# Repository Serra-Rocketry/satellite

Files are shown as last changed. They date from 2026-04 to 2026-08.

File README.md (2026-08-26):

# Helike — PocketQube Mission (#213 - LASC 2026)





PocketQube satellite project by **Serra Rocketry Team** for the Latin American
Space Challenge (LASC) 2026. Focus on bioinspired autorotating recovery system
(SRAB) and LoRa-based telemetry triangulation.

## Overview

The Helike satellite collects flight telemetry (IMU, barometric data, GPS)
and transmits it via LoRa radio at 915 MHz to a ground station. The payload
is a passive autorotating recovery system inspired by maple seed aerodynamics.

## Features

- BME280 environmental sensor (temperature, pressure, humidity)
- ICM-20602 6-axis IMU (accelerometer + gyroscope)
- NEO-8M GPS receiver (position, altitude, time)
- RFM95W LoRa radio (915 MHz, SF7, 125 kHz)
- SD card (primary) + LittleFS (fallback) data logging
- 18-field CSV telemetry packet format
- Vertical velocity computation (EMA filter)
- Automatic apogee detection
- Data validation (NaN + physical range checks)
- 5 Hz sample rate

## Hardware Requirements

| Component | Model | Interface |
|---|---|---|
| MCU | ESP32-C3 Super Mini | - |
| Barometric | BME280 (or BMP280) | I2C (0x76) |
| IMU | ICM-20602 | I2C (0x69) |
| GPS | NEO-8M | UART (9600 baud) |
| Radio | RFM95W | SPI (915 MHz) |
| Storage | microSD card + LittleFS | SPI / flash |

## Software Requirements

- [PlatformIO](https://platformio.org/) (VS Code extension or CLI)
- Python 3.8+ (for analysis scripts in `extras/`)

Dependencies managed automatically by PlatformIO:

| Library | Version |
|---|---|
| sandeepmistry/LoRa | ^0.8.0 |
| Adafruit BME280 Library | ^2.2.4 |
| Adafruit BMP280 Library | ^2.6.8 |
| TinyGPSPlus | ^1.0.3 |

## Quick Start

### 1. Build the Firmware

```bash
pio run -e helike_esp32c3
```

### 2. Upload to Satellite

```bash
pio run -e helike_esp32c3 -t upload --upload-port /dev/ttyACM0
```

### 3. Monitor Serial Output

```bash
pio device monitor -b 115200
```

### 4. Run Unit Tests

```bash
pio test -e native
```

## Repository Structure

```text
satellite/
├── src/                       # Main firmware source
│   ├── main.cpp               # Entry point (setup + loop)
│   ├── config.h               # Global configuration
│   ├── sensors/               # Sensor drivers (ISensor interface)
│   │   ├── BME280Sensor.h/.cpp
│   │   ├── ICM20602Sensor.h/.cpp
│   │   └── GPSSensor.h/.cpp
│   └── modules/               # System modules
│       ├── LoRaModule.h/.cpp
│       ├── TelemetryModule.h/.cpp
│       ├── FilesystemModule.h/.cpp
│       ├── LEDModule.h/.cpp
│       └── BuzzerModule.h/.cpp
├── lib/calc/                  # Header-only calculation library
│   ├── SensorData.h
│   ├── VerticalVelocity.h
│   ├── ApogeeDetection.h
│   └── DataValidation.h
├── test/                      # Native unit tests (Unity)
│   ├── test_vz/
│   ├── test_apogee/
│   └── test_validation/
├── test_hardware/             # Hardware validation sketches
│   ├── sensor/                # Isolated sensor tests
│   ├── integration/           # Multi-sensor integration
│   └── storage/               # Filesystem tests
├── docs/                      # Documentation
│   ├── software.md
│   ├── hardware.md
│   ├── firmware.md
│   ├── flowchart.md
│   └── adr/                   # Architecture Decision Records
├── extras/
│   └── wing-analysis/         # SRAB aerodynamic study
├── hardware/                  # CAD and PCB files
└── platformio.ini             # PlatformIO configuration
```

## Documentation

| Document | Description |
|---|---|
| [Software Architecture](docs/software.md) | Module structure, data flow, validation |
| [Hardware Specs](docs/hardware.md) | Pinout, sensors, LoRa configuration |
| [Firmware Guide](docs/firmware.md) | Build, upload, testing, debug |
| [Flowcharts](docs/flowchart.md) | System diagrams (Mermaid) |
| [ADRs](docs/adr/) | Architecture Decision Records |
| [Hardware Tests](test_hardware/docs/) | Bench guides and checklists |
| [Wing Analysis](extras/wing-analysis/docs/) | SRAB aerodynamics |

## Development Workflow

1. Validate individual sensors in `test_hardware/sensor/`
2. Run integration tests in `test_hardware/integration/`
3. Execute unit tests: `pio test -e native`
4. Run aerodynamic studies: `extras/wing-analysis/`
5. Consolidate results in technical documentation
6. Integrate final firmware

## Quality Tools

```bash
# Markdown linting
npx -y markdownlint-cli "README.md" "docs/**/*.md" "test_hardware/docs/**/*.md" "extras/**/*.md" "hardware/**/*.md"

# Native unit tests
pio test -e native
```

## License

MIT License — see LICENSE file for details.

## Team

**Serra Rocketry Team** — Missão Helike (#213 - LASC 2026)

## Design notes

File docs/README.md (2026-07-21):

# Documentation

Technical documentation for the Helike PocketQube satellite (#213 - LASC 2026).

## Contents

| Document | Description |
|---|---|
| [software.md](software.md) | Software architecture, modules, and data flow |
| [hardware.md](hardware.md) | Hardware specifications, pinouts, and BOM |
| [firmware.md](firmware.md) | Firmware build and deployment guide |
| [flowchart.md](flowchart.md) | System flowcharts (Mermaid diagrams) |
| [adr/](adr/) | Architecture Decision Records |

## Architecture Decision Records

| ADR | Title | Status |
|-----|---|---|
| [ADR-001](adr/001-no-fsm-no-sleep.md) | No FSM, No Sleep Mode | Accepted |
| [ADR-002](adr/002-sd-littlefs-fallback.md) | SD Primary + LittleFS Fallback | Accepted |
| [ADR-003](adr/003-tinygpsplus-vs-manual.md) | TinyGPSPlus vs Manual NMEA | Accepted |
| [ADR-004](adr/004-platformio-vs-arduino-ide.md) | PlatformIO vs Arduino IDE | Accepted |

## Related Documentation

- [Hardware tests](../test_hardware/docs/) — Bench guides and checklists
- [Wing analysis](../extras/wing-analysis/docs/) — SRAB aerodynamic study
- [Mechanical assembly](../hardware/mechanical/README.md) — CAD file structure

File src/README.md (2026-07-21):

# Firmware Source Code

Main source code for the Helike PocketQube satellite.

## Organization

### `sensors/`
Contains drivers and abstractions for the hardware sensors. Every sensor implements the `ISensor` interface for consistent data retrieval.
- `BME280Sensor`: Pressure, Temperature, Humidity.
- `ICM20602Sensor`: Accelerometer and Gyroscope.
- `GPSSensor`: Position and Timing.

### `modules/`
High-level system modules that orchestrate hardware and logic:
- `LoRaModule`: Manages radio transmission and packet formatting.
- `TelemetryModule`: Collects data from sensors and prepares it for storage/transmission.
- `FilesystemModule`: Handles dual-storage logic (SD card primary, LittleFS fallback).
- `LEDModule` & `BuzzerModule`: System status and alert indicators.

## Entry Point

The `main.cpp` file handles the system initialization and the primary execution loop, coordinating the telemetry sampling and transmission cycles.

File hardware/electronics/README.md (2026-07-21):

# Electronics Hardware

This directory contains the electrical design files for the Helike satellite, including schematics and PCB layouts.

## Project Structure

```text
electronics/
├── electronics.kicad_pro   # KiCad project file
├── electronics.kicad_sch   # Circuit schematic
├── electronics.kicad_pcb    # PCB layout
├── electronics.pretty/      # Custom footprints
└── Library.pretty/         # Local component library
```

## Design Notes

- **MCU**: ESP32-C3 Super Mini
- **Interface**: I2C for sensors, SPI for LoRa and SD Card, UART for GPS.
- **Tools**: Designed using KiCad 8.0.

For the mechanical integration of the PCB, see `hardware/mechanical/electronics/`.

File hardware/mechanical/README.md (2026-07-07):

# Mechanical Assembly

Arquivos de modelagem 3D e montagem mecanica do satelite.

## Estrutura de pastas

```
mechanical/
├── assembly/        — montagens gerais (.SLDASM)
├── chassis/         — corpo principal (.SLDPRT)
├── electronics/     — PCBs, bateria, suportes de montagem (.SLDPRT)
├── standoff/        — parafusos, porcas, separadores (.SLDPRT)
├── srab/
│   ├── assembly/    — montagens do SRAB (.SLDASM)
│   └── parts/       — pecas do SRAB (.SLDPRT)
├── README.md
```

## Convencoes

- `.SLDPRT` — partes nativas SolidWorks
- `.SLDASM` — montagens nativas SolidWorks
- `.STEP` — formato neutro para compartilhamento (AP214)
- `.STL` — para impressao 3D / visualizacao rapida
- Nomes em lowercase, snake_case, sem espacos; sufixo `_v2`, `_v3` para revisoes

## Como contribuir

1. Salve `.SLDPRT`/`.SLDASM` nativo + `.STEP` neutro + `.STL` (se impressivel)
2. Mantenha o STEP neutro sempre atualizado como fonte de verdade para corte/CAM
3. Adicione nota aqui quando subir nova revisao

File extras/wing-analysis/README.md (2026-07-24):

# Helike #213 — SRAB Deploy Simulation

Modelagem e simulação do sistema de recuperação SRAB (Samara Recovery
System) para o PocketQube Helike #213 — LASC 2026.

## Notebook principal

[`notebooks/01_simulacao_deploy_srab.ipynb`](notebooks/01_simulacao_deploy_srab.ipynb)
— Pipeline completo de simulação:

| Fase | Veículo | Método |
|---|---|---|
| Stage 1 | Foguete completo | RocketPy `Flight` (subida até apogeu) |
| Stage 2 | Foguete vazio | RocketPy `Flight` + `initial_solution` (descida c/ paraquedas) |
| Stage 3 | PocketQube (payload) | `SRABRecovery.simulate_from_flight()` (descida SRAB) |

## Estrutura

```
wing-analysis/
├── notebooks/
│   └── 01_simulacao_deploy_srab.ipynb   ← Notebook principal (único)
├── src/
│   ├── samara_pq_simulation.py           ← Módulo de simulação SRAB
│   ├── rocketpy_samara/
│   │   ├── srab_recovery.py              ← Recuperação SRAB
│   │   └── plotting.py                   ← Plotagem LRR
│   └── ...
├── geometry/
│   └── Asa3.DXF                          ← Geometria da asa SRAB
├── docs/
│   ├── readme-explicativo.md
│   └── ...
└── data/                                 ← Dados de motor, etc.
```

## Requisitos

- Python 3.10+
- `rocketpy` (>= 1.x)
- `numpy`, `matplotlib`, `scipy`, `folium`

## Execução

```bash
cd notebooks/
jupyter notebook 01_simulacao_deploy_srab.ipynb
```

Ou via nbconvert:

```bash
jupyter nbconvert --to notebook --execute \
  notebooks/01_simulacao_deploy_srab.ipynb \
  --output executed.ipynb
```

## Parâmetros principais

- **Target velocidade**: 20 m/s ÷ SF 1.5 = **13.33 m/s** (SF sobre limite estrutural/LASC)
- **Raio otimizado**: **7.88 cm** (ala Asa3.DXF, 2 asas, β=5°)
- **Paraquedas foguete**: Main (cd_s=7.2) acionado no apogeu (drogue removido)
- **Atmosfera**: GFS forecast (vento real do modelo)
- **Motor**: Cesaroni Pro75 M1670 (placeholder — Calisto)

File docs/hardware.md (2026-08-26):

# Hardware Specifications

## Platform

- **Microcontroller**: ESP32-C3 Super Mini (RISC-V single-core, 400KB RAM)
- **Radio**: RFM95W LoRa module (915 MHz, SPI)
- **GPS**: NEO-8M (UART, 9600 baud)
- **Sensors**: BME280 (I2C, primary) with BMP280 fallback, ICM-20602 (I2C)
- **Storage**: SD card slot (GPIO10, SPI) + LittleFS flash (fallback)
- **Actuators**: LED (GPIO3), Active buzzer (GPIO0)

## Pinout (ESP32-C3 Super Mini — per schematic)

```text
                     ESP32-C3 Super Mini
  ┌─────────────────────────────────────────────┐
  │  0  BUZZER ─────────── Active buzzer        │
  │  1  RESET ──────────── RFM95W (LoRa RST)    │
  │  2  DIO0 ───────────── RFM95W (LoRa IRQ)    │
  │  3  LED ────────────── Status indicator     │
  │  4  SCK ─── SPI ────── RFM95W + SD Card     │
  │  5  MISO ── SPI ────── RFM95W + SD Card     │
  │  6  MOSI ── SPI ────── RFM95W + SD Card     │
  │  7  NSS ────────────── RFM95W (LoRa CS)     │
  │  8  SDA ─── I2C ────── BME280 + ICM-20602   │
  │  9  SCL ─── I2C ────── BME280 + ICM-20602   │
  │ 10  CS_SD ──────────── SD Card (CS)          │
  │ 20  TX_GPS ── UART ─── GPS NEO-8M (TX)      │
  │ 21  RX_GPS ── UART ─── GPS NEO-8M (RX)      │
  └─────────────────────────────────────────────┘
```

### Pin Summary Table

| GPIO | Label | Function / Protocol | Connected To |
|---|---|---|---|
| 0 | BUZZER | GPIO (digitalWrite) | Active buzzer |
| 1 | RESET | GPIO output | RFM95W (pin 6, RST) |
| 2 | DIO0 | GPIO input (IRQ) | RFM95W (pin 14, DIO0) |
| 3 | LED | GPIO output | Status indicator |
| 4 | SCK | SPI Clock | RFM95W + SD Card |
| 5 | MISO | SPI MISO | RFM95W + SD Card |
| 6 | MOSI | SPI MOSI | RFM95W + SD Card |
| 7 | NSS | SPI Chip Select | RFM95W (LoRa CS) |
| 8 | SDA | I2C Data | BME280 + ICM-20602 |
| 9 | SCL | I2C Clock | BME280 + ICM-20602 |
| 10 | CS_SD | SPI Chip Select | SD Card module (CS) |
| 20 | TX_GPS | UART RX (ESP input) | GPS NEO-8M (TX pin) |
| 21 | RX_GPS | UART TX (ESP output)| GPS NEO-8M (RX pin) |

### Notes

- **SPI bus is shared** between RFM95W and SD Card (same MOSI/MISO/SCK). Each has a
  dedicated CS pin: LoRa CS = GPIO7, SD CS = GPIO10.
- **I2C bus is shared** between BME280/BMP280 and ICM-20602. Both use address 0x76
  (BME/BMP) and 0x69 (ICM).
- **UART**: GPS uses Serial1 with custom pins RX=GPIO20, TX=GPIO21.
- **Buzzer**: Active buzzer (built-in oscillator) — controlled via `digitalWrite`.
  No PWM required.

## Sensor Specifications

### BME280/BMP280 (Environmental — BMP280 fallback)

| Parameter | Value |
|---|---|
| Interface | I2C |
| Address | 0x76 (SDO=GND) or 0x77 (SDO=VCC)  |
| Pressure range | 300-1100 hPa |
| Temperature range| -40 to +85°C |
| Humidity range | 0-100% RH (BME280 only, N/A on BMP280) |
| I2C speed | 400 kHz (Fast Mode) |

**Fallback strategy**: The firmware tries BME280 first. If not found, falls back
to BMP280. `getHumidity()` returns NAN when using BMP280 (no humidity sensor).

### ICM-20602 (IMU)

| Parameter | Accelerometer | Gyroscope |
|---|---|---|
| Interface | I2C | I2C |
| Address | 0x69 | 0x69 |
| Range | ±16g (±157 m/s²) | ±2000°/s (±34.9 rad/s)|
| Resolution  | 16-bit | 16-bit |
| Sensitivity | 2048 LSB/g | 16.384 LSB/°/s |

### NEO-8M (GPS)

| Parameter | Value |
|---|---|
| Interface | UART (Serial1) |
| Baud rate | 9600 |
| Protocol | NMEA 0183 |
| Update rate | 1 Hz (default) |
| Fix types | 2D, 3D |
| Min satellites | 4 (3D fix) |

### RFM95W (LoRa Radio)

| Parameter | Value |
|---|---|
| Interface | SPI |
| Frequency | 915 MHz |
| Sync Word | 0xF3 |
| Spreading Factor| 7 |
| Bandwidth | 125 kHz |
| Coding Rate | 4/5 |
| CRC | Enabled |
| TX Power | 20 dBm |

## LoRa Compatibility

Satellite and receiver MUST use identical LoRa parameters:

| Parameter | Satellite | Receiver |
|---|---|---|
| Frequency | 915 MHz | 915 MHz  |
| Sync Word | 0xF3 | 0xF3 |
| SF | 7 | 7 |
| BW | 125 kHz | 125 kHz  |
| CR | 4/5 | 4/5 |
| CRC | Enabled | Enabled  |

## Known ESP32-C3 Issues

### 1. tone() / LEDC Bug
The Arduino core for ESP32-C3 has a bug where `tone()` fails with
`ledc: ledc_get_duty(745): LEDC is not initialized`.
**Fix**: Use `ledcSetup()` + `ledcAttachPin()` + `ledcWrite()` instead of `tone()`.
(The buzzer module uses `digitalWrite` since the active buzzer has a built-in
oscillator — no PWM needed. The bug remains relevant for passive buzzers or
PWM-driven peripherals.)

### 2. USB CDC Serial
`Serial.println()` output does not appear unless the firmware is compiled with:
```
-D ARDUINO_USB_MODE=1 -DARDUINO_USB_CDC_ON_BOOT=1
```
Without these flags, Serial uses UART0 (pins GPIO20/21) instead of USB CDC.

### 3. I2C Bus Recovery
`resetI2C()` (toggling SCL via pinMode/digitalWrite) breaks the I2C peripheral
configuration on ESP32-C3. **Do not use GPIO-level recovery with TwoWire.**

### 4. Shared SPI Bus: SD + LoRa (bench session 2026-08-24)

The SD card and RFM95W share SCK/MISO/MOSI. Three rules discovered during
first power-on testing (full rationale in ADR-005):

- **Initialize SPI exactly once** in `main.cpp`, with CS pins HIGH, before
  any library touches the bus. Libraries (`SD`, LoRa sandeepmistry) call
  `SPI.begin()` internally on their own `begin()`; a second init corrupts
  the peripheral state.
- **Boot order: LoRa first, storage after.** An SD mount attempt before
  radio configuration makes every subsequent `endPacket()` fail. The
  reverse order is safe: after a failed `SD.begin()`, TX still works.
- **Never call `SD.end()` or re-`begin()` SPI at runtime.** Both tear down
  the peripheral shared with the radio.

Additional SD notes:
- SD mount needs ≥74 wake-up clocks with CS high before CMD0;
  `FilesystemModule::setupSD()` sends them manually.
- If `appendLine()` fails 5× consecutively in flight, the module degrades
  to LittleFS automatically (no code path requires SD).
- Cards must be FAT32; exFAT mounts fail with `f_mount failed (13)`.
- **Wiring**: long untwisted dupont jumpers between ESP and RFM95W cause
  intermittent SPI corruption (worked/failed depending on cable position).
  Keep SPI leads short (<10 cm); if twisted pairs are used, twist each
  signal with GND, never signal-with-signal.

### 5. LoRa sandeepmistry Library API Notes

- `LoRa.endPacket()` returns **1 on success**, 0 on failure. Check
  `== 1`. (A pre-existing inverted check reported every successful TX as
  an error for the module's whole early life.)
- Use `LoRa.setSPI(SPI)` before `LoRa.setPins()` so the library shares
  the bus instance initialized by `main.cpp`.

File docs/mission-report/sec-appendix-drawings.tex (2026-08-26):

\textbf{\hfill\break
}

\textbf{Engineering Drawings and Optional Appendix}

This appendix contains the revision-controlled technical drawings and
optional supporting material for the Helike \#213 subsystems.

\subsection{Drawing List}

\begin{center}
{\small
\setlength{\tabcolsep}{6pt}
\begin{tabularx}{\linewidth}{>{\raggedright}p{6cm}X}
\toprule
\textbf{Drawing / Document} & \textbf{Status} \\
\midrule
Electrical schematic (KiCad, U1--U6, SW1--SW3) & Final (Figure 1) \\
PCB layout & In progress \\
SRAB wing geometry (Asa1/Asa2/Asa3) & Final (DXF + ABS prototypes) \\
PocketQube 1P mechanical structure & In progress \\
ESP32-C3 pinout & Final \\
Integrated assembly & In progress \\
\bottomrule
\end{tabularx}
}
\end{center}

\subsection{Optional Appendices}

\subsubsection{SRAB Wing Geometry}

The wing geometries evolved through three design iterations, driven
by the simulation-to-field comparison loop described in Section 4:

\begin{itemize}
\item \textbf{Asa1} — 4 wings, first prototype: v$_{impact}$ =
  10.33~m/s, 444.9~rpm, 6.1$^{\circ}$.
\item \textbf{Asa2} — 4 wings, increased area and realignment:
  v$_{impact}$ = 10.05~m/s, 439.1~rpm, 11.9$^{\circ}$ — candidate
  configuration.
\item \textbf{Asa3} — 2 wings (mission final): reduced mass and
  complexity, $v \approx 20$~m/s, within the SCSM 20--45~m/s range.
\end{itemize}

% TODO: insert dimensional drawings of the SRAB wings (DXF-derived),
% the PCB layout, the mechanical structure and the integrated assembly
% as they become available.

\subsubsection{Test Data}

% TODO: include CSV logs, telemetry plots, simulation-vs-field
% comparison plots, photos of Asa1/Asa2 prototypes and drop-test
% videos once the instrumentation campaign (Test 4, ~200 m) is
% complete.

\subsubsection{Computational Simulation}

The 4th-order autorotation model, calibrated parameters, simulation
scripts (RocketPy + SRAB extension) and the geometry heat-map are
maintained in the repository under \texttt{extras/wing-analysis/}.
The full-flight simulation (Dédalo + SRAB) is documented in the
notebook \texttt{01\_simulacao\_dedalo.ipynb}.

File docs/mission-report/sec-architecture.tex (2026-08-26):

\begin{enumerate}
\def\labelenumi{\arabic{enumi}.}
\setcounter{enumi}{1}
\item
  \textbf{System Architecture and Concept of Operations}
\end{enumerate}

\subsection{System Architecture}

Helike \#213 is a PocketQube 1P (50$\times$50$\times$50~mm, $\sim$200~g)
whose central subsystem is the SRAB — the bioinspired autorotative
recovery system. The satellite is organized in five functional blocks:

\begin{center}
{\small
\setlength{\tabcolsep}{6pt}
\begin{tabularx}{\linewidth}{>{\raggedright}p{3cm}X}
\toprule
\textbf{Block} & \textbf{Components} \\
\midrule
Recovery (SRAB) & 2 autorotative wings (Asa3), passive deployment \\
EPS & Li-Ion 1300~mAh + BMS, RBF pin, 2 kill switches \\
Avionics & ESP32-C3 Super Mini, single 5~Hz polling loop \\
Sensors & BME280 (pressure/temp/humidity), ICM-20602 (6-axis IMU) \\
Telemetry & LoRa RFM95W 915~MHz, GPS NEO-8M, SD + LittleFS \\
\bottomrule
\end{tabularx}
}
\end{center}

\begin{figure}[htbp]
\centering
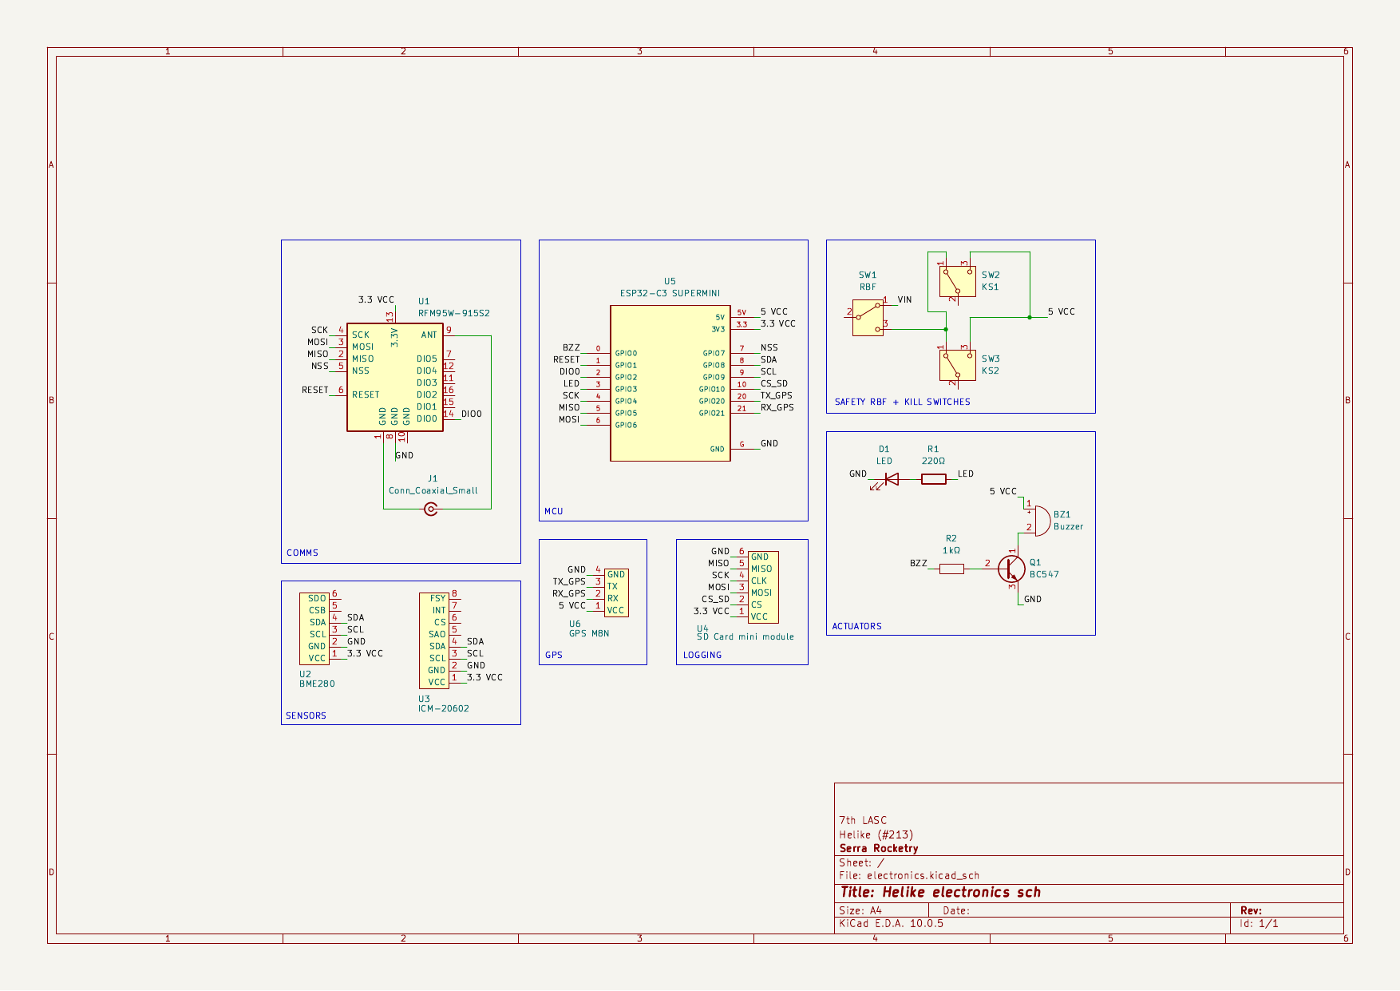
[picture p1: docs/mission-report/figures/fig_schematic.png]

\caption{Electrical schematic of Helike \#213 (KiCad). U1: ESP32-C3
Super Mini; U2: LoRa RFM95W-915S2; U3: BME280; U4: ICM-20602; U5: GPS
NEO-8M; U6: SD card module; SW1/SW2: kill switches (Z axis); SW3: RBF
pin; J1: SMA antenna; D1/BZ1: status LED and buzzer.}
\label{fig:schematic}
\end{figure}

\subsection{Subsystem Descriptions}

\subsubsection{Recovery (SRAB)}

The SRAB is a passive recovery system composed of 2 autorotative wings
(Asa3 geometry), stowed during flight and deployed by ejection. They
convert the potential energy of the fall into rotational kinetic
energy, slowing the satellite to a predicted terminal velocity of
13.33~m/s --- the $V_F = 20/1.5$~m/s design target, applying a 1.5
safety factor to the LASC 20~m/s limit. There are no actuators: no
servo, no pyrotechnics, no deployment electronics. Recovery does not
depend on software at all, so it works even with total loss of the
avionics. The two-wing configuration keeps the mechanism simple and
light; losing a single wing is a mission-critical degradation, so the
design relies on the robustness of the geometry and on the drop-test
evidence accumulated across the Asa1/Asa2/Asa3 iterations.

\subsubsection{Electrical Power System}

Energy comes from a 1300~mAh Li-Ion battery protected by a BMS that
covers overcharge, overdischarge, short-circuit and overcurrent. With
an average draw of about 145~mA, the predicted autonomy exceeds 5~h, a
margin of roughly two times the SCSM requirement of 4~h. Safety is
handled by two kill switches (SW1/SW2, NC contacts wired in parallel,
Z axis) plus the RBF pin
(SW3), which cuts all energy when inserted. The satellite only powers
on at ejection, keeping it independent from the rocket as required by
REC 10.1.1.

\subsubsection{Avionics and Telemetry}

At the core sits an ESP32-C3 Super Mini, a single-core RISC-V
microcontroller running a single synchronous 5~Hz polling loop, with
no state machine and no RTOS scheduler. A BME280 measures pressure,
temperature and humidity, and an ICM-20602 six-axis IMU adds
acceleration and angular rate; together they feed the 5~Hz telemetry
packet and the SRAB rotation analysis. Telemetry goes down through the
LoRa RFM95W at 915~MHz (SF7, 125~kHz bandwidth, 20~dBm, sync word
0xF3, CRC enabled), transmit-only, while a GPS NEO-8M records the
post-landing position. Flight data are written to an SD card with
automatic LittleFS fallback on the internal flash, and three ground
beacons measure RSSI for trilateration once the satellite is on the
ground. Impact detection, the buzzer and the low-power beacon mode are
planned for a future firmware revision and are not yet part of the
flight software.

\subsection{Concept of Operations}

From a technology-development standpoint, the ConOps doubles as the
flight-test plan for the SRAB: each arc exercises one stage of the
recovery system --- powered-off safety while stowed (SAFE), ejection
and power-on (BOOST), passive deployment and autorotation (DESCENT),
and ground location (POST-LANDING) --- and the descent telemetry is
the primary evidence for validating the aerodynamic model against
real flight data.

The satellite's behavior follows the physical flight profile in four
arcs, and the firmware mirrors them through a single polling loop
rather than a phase-detecting state machine. The first arc is
\emph{inert}: the satellite starts in SAFE, with the kill switches and
the RBF pin inserted, and stays completely powered off until ejection.
The second arc begins at \emph{ejection}: the satellite powers on,
initializes the sensors and attempts a first GPS fix, then samples and
transmits through the boost and coast phases while the rocket climbs
toward apogee. The third arc is the \emph{descent}: at apogee the
satellite leaves the rocket, the two SRAB wings deploy passively ---
no actuator, no command required --- and the descent is governed
entirely by autorotation while the 5~Hz telemetry packet streams
rotation rate, descent velocity and the monitored Launch Readiness
Review parameters. The fourth arc is \emph{post-landing}: impact
detection, the buzzer and a low-power beacon mode are planned for a
future firmware revision; the current firmware simply keeps
transmitting periodic packets with RSSI and GPS position until the
battery is exhausted or the recovery team arrives.

\begin{figure}[htbp]
\centering
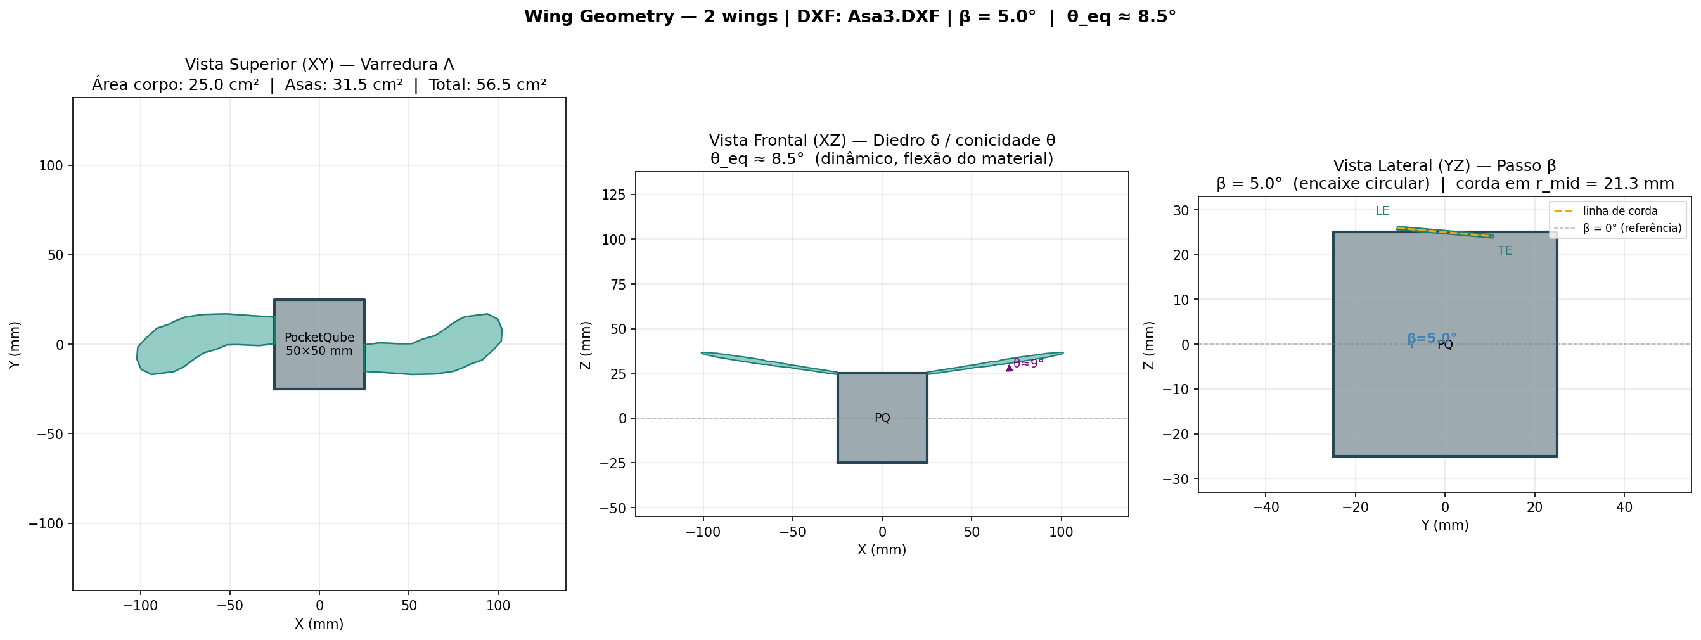
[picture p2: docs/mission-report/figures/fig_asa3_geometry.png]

\caption{SRAB wing geometry views (Asa3): three orthogonal projections
of the wing + hub assembly used in the computational simulation and
drop tests.}
\label{fig:wing-geometry}
\end{figure}

% TODO: replace placeholder figure above with the final CAD renders /
% exploded view once available. fig_asa3_geometry.png is the
% computational geometry used in the SRAB model.

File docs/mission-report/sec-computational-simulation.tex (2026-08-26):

\begin{enumerate}
\def\labelenumi{\arabic{enumi}.}
\setcounter{enumi}{3}
\item
  \textbf{Computational Simulation}
\end{enumerate}

\subsection{Theoretical Background}

\subsubsection{Samara Autorotation}

The SRAB is inspired by the autorotation of samara seeds (\emph{Acer
rubrum}). The seed geometry places the center of mass at one end and
the aerodynamic center at the other, generating a torque imbalance
that produces stable conical rotation during fall. The resulting
motion is a steady autorotation state where the descent rate is
substantially lower than the ballistic terminal velocity of the same
mass [2].

\subsubsection{Leading-Edge Vortex (LEV)}

At high incidence angles and rotation rates, a stable leading-edge
vortex forms on the wing upper surface, increasing the effective lift
coefficient beyond the thin-airfoil limit. This LEV effect is the key
to the samara's efficiency and is modeled through an augmented lift
coefficient in the blade element formulation.

\subsubsection{Reduced-Order Rigid-Body Model}

The descent is modeled with a 4th-order reduced Newton-Euler
formulation [3], with state vector (Eq.~\ref{eq:state}):

\begin{equation}
\mathbf{x} = [\theta,\ \dot{\theta},\ \dot{\phi},\ v_0]^T
\label{eq:state}
\end{equation}

where $\theta$ is the conicity angle, $\dot{\phi}$ the rotor spin rate
and $v_0$ the vertical descent velocity. The aerodynamic loads are
computed with the Blade Element Method (BEM) (Eq.~\ref{eq:bem}):

\begin{equation}
dF = \frac{1}{2}\rho\, w(r)\, \|U\|^2 \left[C_L(\alpha),\; C_D(\alpha)\right] dr
\label{eq:bem}
\end{equation}

with the thin-airfoil lift curve and the induced-drag model
(Eq.~\ref{eq:coefs}):

\begin{equation}
C_L = 2\pi\sin\alpha, \qquad
C_D = C_L \sin\alpha + C_{D0}
\label{eq:coefs}
\end{equation}

where $C_{D0} = 1.0$ is the flat-plate drag coefficient and the LEV
contribution is embedded through the $f_{factor} = 0.3$ correction in
the lift build-up [5].

\subsection{Simulation Methodology}

The validation pipeline is an iterative loop: model, simulate,
prototype, drop, compare, and iterate on the geometry. We start from a
4th-order rigid-body dynamics model with a Blade Element Method
aerodynamic model, implemented in RocketPy [6] with SRAB extension
modules. The descent is then simulated from the real apogee of the
launch vehicle, the Dédalo rocket, in the same GFS atmosphere and with
the same payload mass as the actual flight. PETG 3D-printed wings
(Asa1, Asa2 and Asa3 geometries) are dropped from controlled heights
with instrumentation, and the measured terminal velocity, spin rate
and cone angle are compared against the simulation. The wing geometry
is updated between test cycles based on that comparison, which is how
the design improved from one campaign to the next.

\subsubsection{Launch Vehicle Model — Dédalo}

The Dédalo rocket (used as the launch vehicle for Helike \#213) is
modeled in RocketPy:

\begin{center}
{\small
\setlength{\tabcolsep}{6pt}
\begin{tabular}{>{\raggedright}p{5.2cm}l}
\toprule
\textbf{Parameter} & \textbf{Value} \\
\midrule
Total mass (with payload) & 5.100 kg \\
Empty mass (Stage 2) & 4.900 kg \\
Payload mass (Helike \#213) & 0.200 kg \\
Diameter & 106 mm \\
Motor & SolidMotor, 926 N peak, 2.82 s burn \\
Motor data points & 95 \\
Atmosphere & GFS (real, launch-day forecast) \\
Launch site & lat $-21.94305$, lon $-48.95409$, elev 478 m \\
\bottomrule
\end{tabular}
}
\end{center}

\subsection{Results}

\subsubsection{Stage 1 — Dédalo Ascent (with payload)}

\begin{center}
\begin{tabular}{ll}
\toprule
\textbf{Parameter} & \textbf{Value} \\
\midrule
Apogee & 1520 m AGL (1996 m ASL) \\
Time to apogee & 17.83 s \\
Maximum velocity & 205.3 m/s (0.59 Mach) \\
Maximum acceleration & 106.7 m/s$^2$ (10.9 g) \\
Rail departure & 0.47 s at 18.9 m/s \\
\bottomrule
\end{tabular}
\end{center}

\subsubsection{Stage 2 — Dédalo Empty Descent (parachute CdS = 10.0)}

\begin{center}
\begin{tabular}{ll}
\toprule
\textbf{Parameter} & \textbf{Value} \\
\midrule
Maximum descent velocity & 17.8 m/s \\
Total descent time & 183.5 s \\
Impact position (relative) & x $= -139.7$ m, y $= +43.2$ m \\
\bottomrule
\end{tabular}
\end{center}

\subsubsection{Stage 3 — SRAB Descent from Real Apogee}

The SRAB simulation is initialized at the real apogee of Stage 1
(1520.5 m AGL, $v_z \approx 0$), with the optimized wing radius for
the target impact velocity $V_F^{target} = V_{F,max}/FS =
20/1.5 = 13.33$ m/s:

\begin{center}
\begin{tabularx}{\linewidth}{>{\raggedright}p{5.2cm}X}
\toprule
\textbf{Parameter} & \textbf{Value} \\
\midrule
Wing geometry & Asa3 (2 wings), optimized radius 79.7 mm \\
Release altitude & 1520.5 m AGL \\
Impact velocity & 13.33 m/s \\
Descent time & 111.4 s \\
Equilibrium cone angle $\theta_{eq}$ & 8.6$^{\circ}$ \\
Impact spin rate & 477 RPM \\
Total drift & 184.3 m \\
Impact position (relative) & x $= -67.5$ m, y $= +171.5$ m \\
LASC descent criterion & Target $V_F = V_{F,max}/FS = 20/1.5 = 13.33$ m/s; simulated impact 13.33 m/s (PASS, FS 1.5) \\
\bottomrule
\end{tabularx}
\end{center}

Note that the release occurs at the true apogee of the Dédalo flight
(1520.5~m AGL), about 1.4\% above the 1500~m AGL deployment guideline
of REC 10.1.5; the margin assessment is part of the Launch Readiness
Review.

\begin{figure}[htbp]
\centering
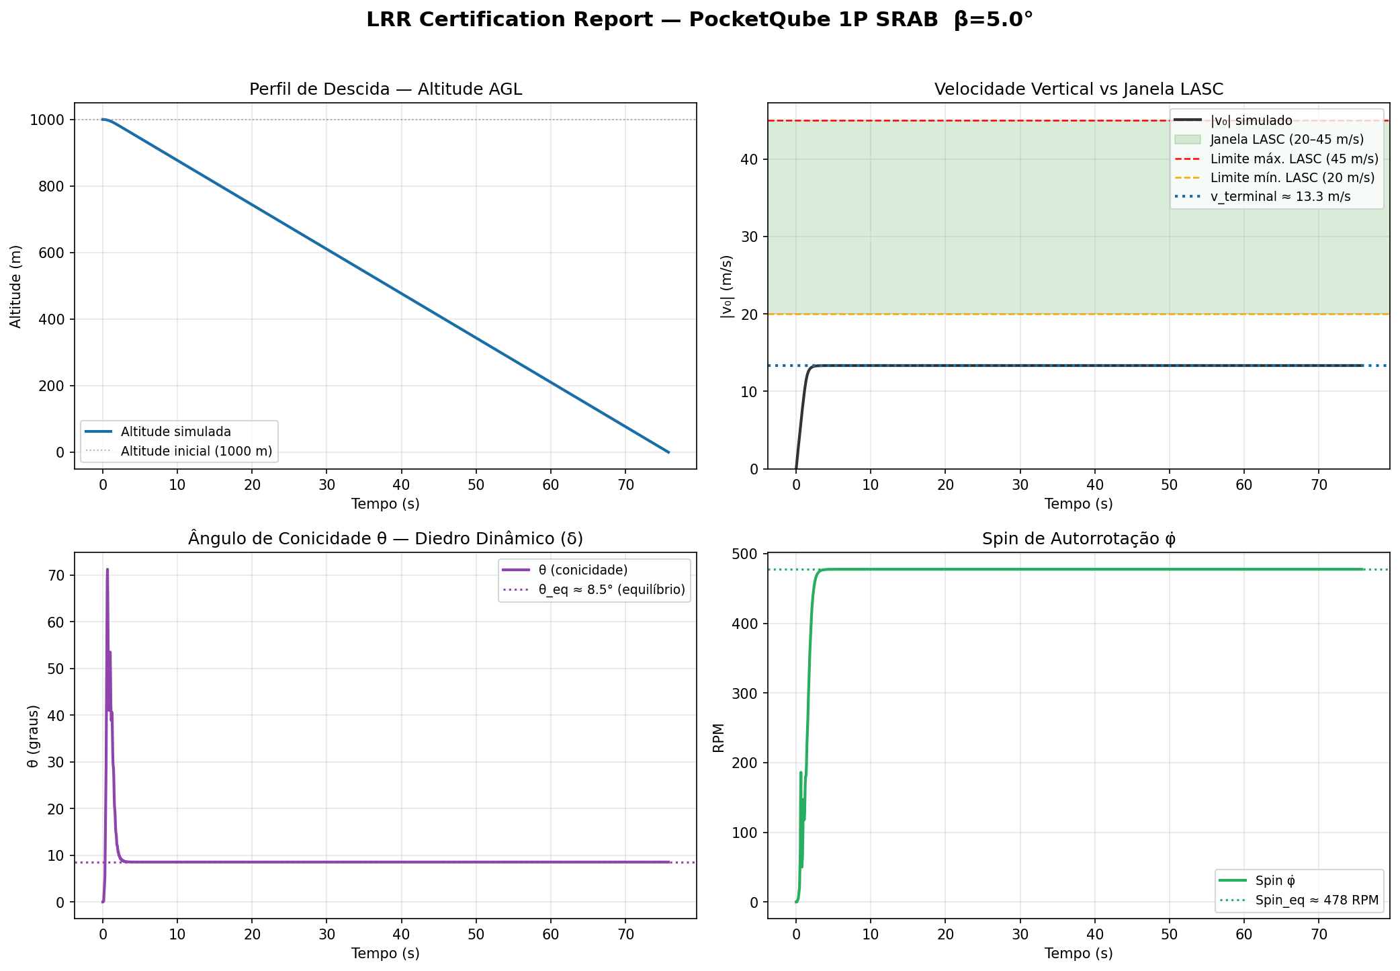
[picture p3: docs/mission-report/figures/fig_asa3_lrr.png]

\caption{LRR certification dashboard for the SRAB descent from the
real apogee: altitude profile, vertical velocity, cone angle
$\theta$, and autorotation spin rate.}
\label{fig:lrr-asa3}
\end{figure}

\begin{figure}[htbp]
\centering
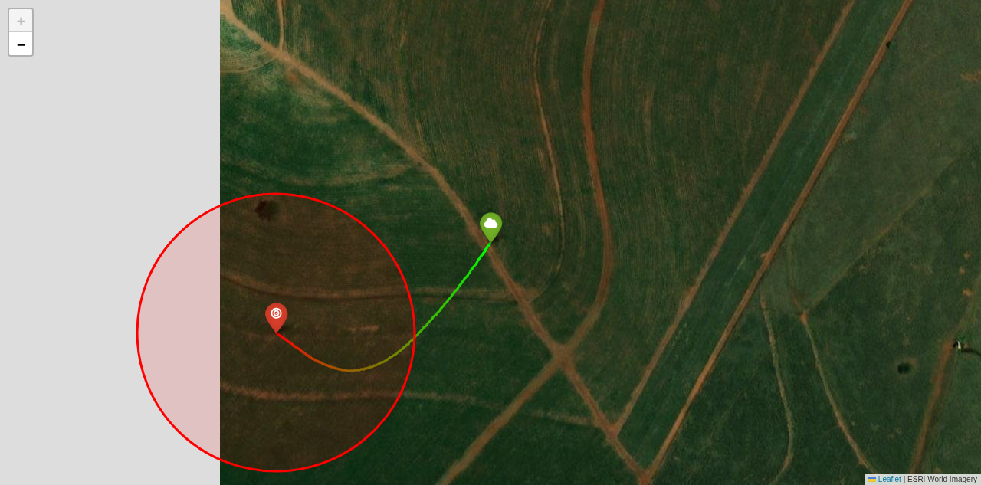
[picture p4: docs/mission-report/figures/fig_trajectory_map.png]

\caption{Satellite view of the simulated SRAB descent trajectory over
the Dédalo launch site: release point (green marker) at apogee and
predicted impact point (red marker, 100~m radius circle) downrange;
the trajectory line is colored by altitude.}
\label{fig:trajectory-map}
\end{figure}

\subsubsection{SRAB vs. Parachute Comparison}

A flat circular parachute ($\varnothing$200 mm, $C_D = 1.5$) was
simulated in the same GFS atmosphere, same release conditions and same
payload mass, as a benchmark:

\begin{center}
\begin{tabular}{lrrr}
\toprule
\textbf{Parameter} & \textbf{SRAB} & \textbf{Parachute} & \textbf{Ratio} \\
\midrule
Impact velocity (m/s) & 13.33 & 8.48 & 1.57$\times$ \\
Descent time (s) & 111.4 & 174.6 & 0.64$\times$ \\
Total drift (m) & 131.2 & 204.6 & 0.64$\times$ \\
Impact energy (J) & 17.8 & 7.2 & 2.47$\times$ \\
Terminal velocity (SL) (m/s) & 13.33 & 8.24 & 1.62$\times$ \\
\bottomrule
\end{tabular}
\end{center}

\begin{figure}[htbp]
\centering
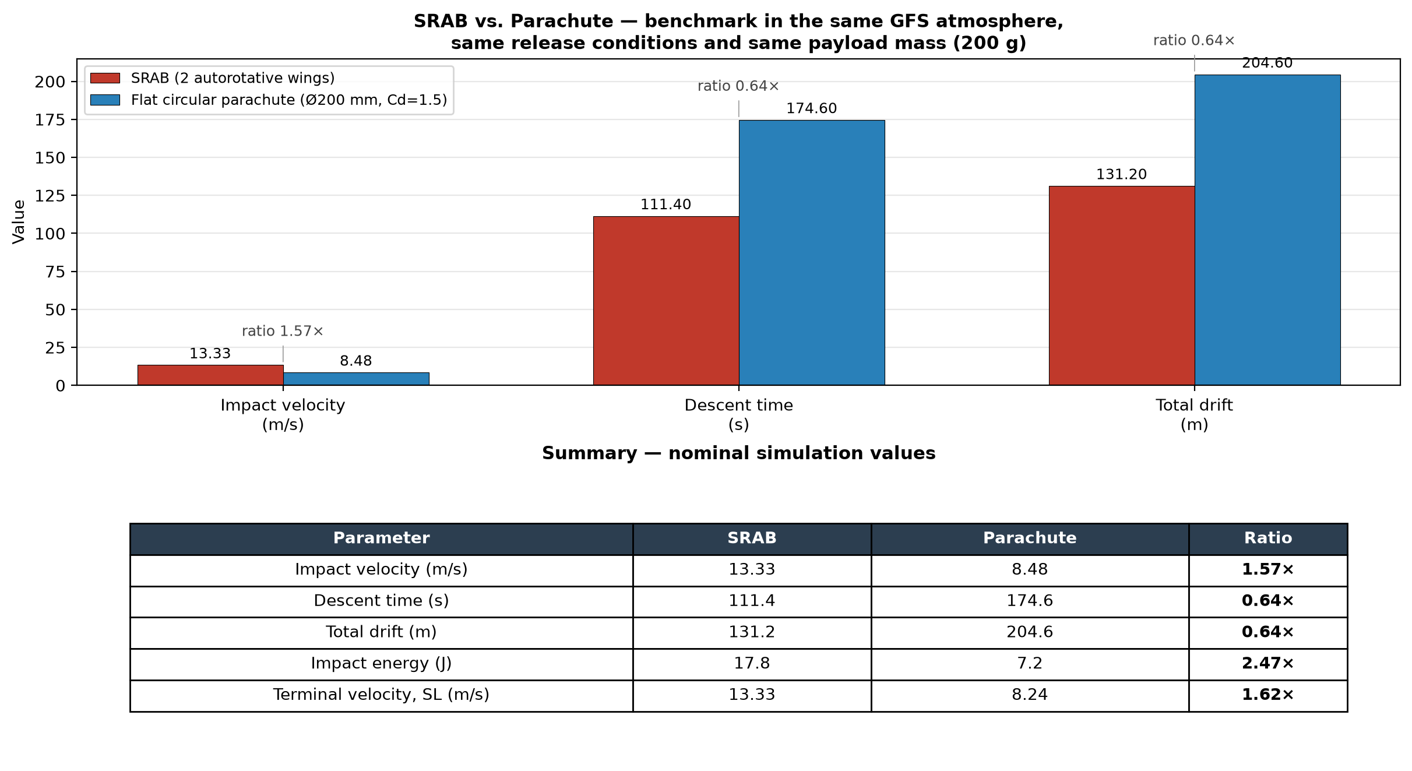
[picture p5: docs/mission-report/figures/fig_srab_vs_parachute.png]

\caption{SRAB vs. parachute benchmark in the same GFS atmosphere, same
release conditions and same payload mass (200~g): impact velocity,
descent time and total drift (bars) and full numerical summary
(table). Values match the comparison table above.}
\label{fig:srab-vs-parachute}
\end{figure}

The SRAB achieves a 36\% shorter descent time and 36\% lower drift
than the parachute, at the cost of a higher impact velocity and
energy — both still well below the 20~m/s LASC limit. The shorter
descent reduces wind exposure (drift), which is the dominant factor
for recovery accuracy on miniaturized satellites.

\subsubsection{Robustness: Monte Carlo Analysis}

A Monte Carlo analysis with 100 iterations of the Asa3 2-wing
configuration, released from the real simulated apogee, assessed the
descent under atmospheric dispersion: the impact velocity stayed at
$13.33 \pm 0.31$~m/s (P5 12.78, P95 13.87), the descent time at
$110.97 \pm 2.53$~s, the spin rate at $475.9 \pm 12.8$~rpm and the
equilibrium cone angle at $8.63 \pm 0.67^{\circ}$ — every iteration
below the 20~m/s LASC limit, confirming the 1.5 safety factor.

\subsubsection{Experimental Drop Tests}

Three instrumented drop-test campaigns validated the model:

\begin{center}
\begin{tabular}{llll}
\toprule
\textbf{Test} & \textbf{Geometry} & \textbf{v impact} & \textbf{Spin / Cone} \\
\midrule
Test 1 & Asa1, 4 wings & 10.33 m/s & 306.8 rpm / 13.5$^{\circ}$ \\
Test 2 & Asa2, 4 wings & 10.05 m/s & 306.9 rpm / 24.4$^{\circ}$ \\
Test 3 & Asa3, 4 wings & 12.90 m/s & 372.0 rpm / 17.2$^{\circ}$ \\
\bottomrule
\end{tabular}
\end{center}

Test 2 (Asa2, 4 wings, wing area 122.28~cm$^2$) increased the wing
area by 12\% and reduced the impact velocity from 10.33 to 10.05~m/s
(4\_PU), becoming the intermediate candidate. Test 3 (Asa3, 4 wings,
1000~m drop) reached steady autorotation at 12.90~m/s in 78.03~s,
with $\theta_{eq} = 17.22^{\circ}$ and 371.98~rpm, dissipating 99.15\%
of the impact energy (ENMC consolidated data).

\begin{figure}[htbp]
\centering
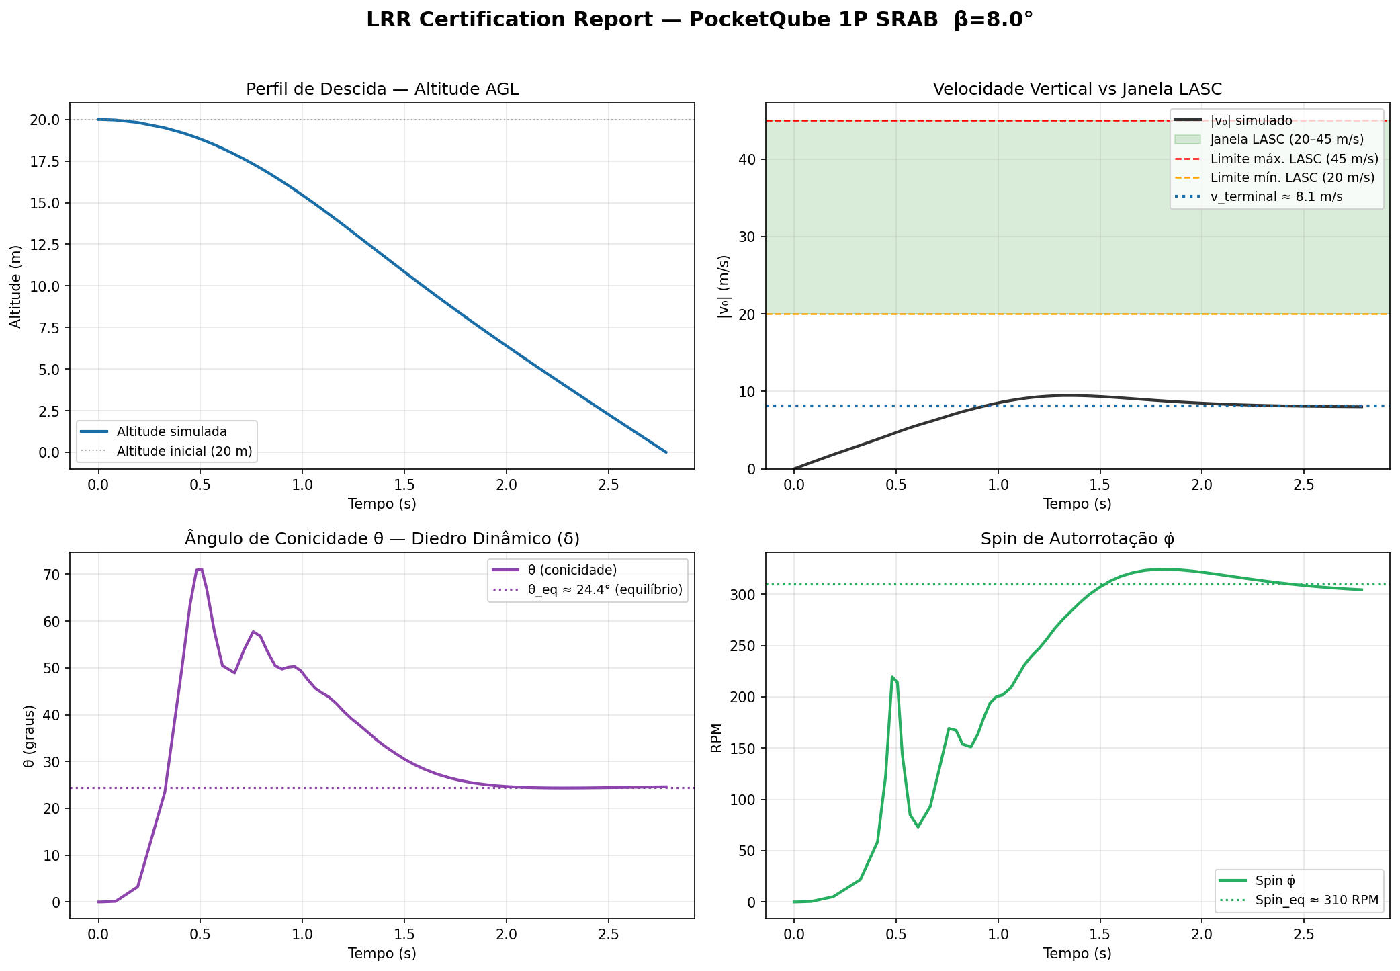
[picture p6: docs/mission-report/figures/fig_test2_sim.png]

\caption{Drop test 2 (Asa2, 4 wings) LRR dashboard: measured descent
profile, vertical velocity, cone angle and spin rate.}
\label{fig:test2-lrr}
\end{figure}

Test 3 (Asa3, 4 wings) also validated the onboard electronics, with
the SRAB instrumented to record rotation with the flight IMU; at a
1000~m drop it reached steady autorotation at 12.90~m/s in 78.03~s,
with $\theta_{eq} = 17.22^{\circ}$ and 371.98~rpm, dissipating 99.15\%
of the impact energy (ENMC consolidated data).

\subsubsection{Geometry Comparison and Final Choice}

A comparative simulation of Asa2 (4 wings) vs. Asa3 (2 wings) showed
10.05 vs. 13.33~m/s terminal velocity after the radius optimization.
The Asa3 2-wing configuration (optimized aerodynamic radius
79.7~mm) was chosen as the final configuration for the mission: it
reaches the 20/1.5~m/s design target with a 1.5 safety factor on the
LASC 20~m/s limit, while offering lower mass and complexity than the
4-wing versions.

% TODO: Test 4 (~200 m drop) is the next step for quantitative
% aerodynamic validation of the Asa3 2-wing configuration.

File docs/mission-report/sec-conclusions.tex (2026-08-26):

\begin{enumerate}
\def\labelenumi{\arabic{enumi}.}
\setcounter{enumi}{4}
\item
  \textbf{Conclusions and Lessons Learned}
\end{enumerate}

\subsection{Conclusions}

The Helike \#213 mission demonstrates that a bioinspired autorotative
recovery system (SRAB) is a viable, simpler and more robust
alternative to conventional parachutes for 1P PocketQubes. The SRAB
reaches the LASC regulatory impact velocity with a fully passive
mechanism, with no actuators, no pyrotechnics and no software
dependency. The computational model, built on a 4th-order rigid body
with BEM and a LEV correction, reproduces the measured drop-test
behavior with enough fidelity for design decisions, and the full
flight simulation, from the Dédalo launch vehicle to the SRAB descent
under real GFS conditions, certifies the recovery. Against a
conventional parachute, the SRAB shortens the descent by 36\% and cuts
total drift by 36\%, which improves recovery accuracy at the cost of a
higher, yet compliant, impact energy. Finally, the three-filter review
(SCSM compliance, Murphy analysis, timeline discipline) proved to be
an effective engineering framework: it caught the non-parachute
notification requirement (REC 10.2.1), drove the redundancy decisions
in firmware and hardware, and kept the project aligned with the
competition deadlines.

Above all, the mission treats LASC not merely as a competition but as
the operational proving ground of the SRAB technology: the September
flight is the first full-scale, instrumented test of a passive
samara-inspired recovery system in the conditions for which it was
designed. The telemetry returned from the descent --- rotation rate,
descent velocity, impact conditions --- is the evidence that will
recalibrate the model parameters (e.g.\ $C_{D0}$ and the LEV
correction factor) and close the loop between simulation and flight,
advancing the SRAB from a computational concept to a flight-proven
technology available to future PocketQube missions.

\subsection{Lessons Learned}

LASC 2025 taught us that optimization without redundancy is a trap,
and every subsystem of Helike carries a backup path: SD with LittleFS,
LoRa with local storage, a hardware watchdog, and a passive recovery
system that does not depend on electronics at all. We learned that the
parachute is the weakest link in the recovery chain, and replacing it
with a passive aerodynamic mechanism removes the most failure-prone
element entirely. Iterative drop testing beat simulation alone: each
test cycle, from Asa1 to Asa2 to Asa3, produced a measurable
improvement in both the model and the design, and that
simulation-validated iteration loop became the core of the project
methodology. Compliance, we found, is a design input, not a formality;
the SCSM requirements on kill switches, RBF, autonomy and notification
shaped the hardware schematic and the firmware loop architecture from day one. On
the team side, the three-filter reviews force decisions backed by
evidence (videos, logs, bench tests), which accelerates the transfer
of knowledge from senior to new members: every filter review doubles
as training for the next generation of the team.

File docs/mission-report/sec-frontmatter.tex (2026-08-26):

\textbf{Abstract}

This report presents the development of the Helike \#213 1P PocketQube
satellite, designed by team Serra Rocketry (IPRJ-UERJ) for the
Satellite Challenge category of the 7th Latin American Space Challenge
(LASC 2026). The mission's central element is the SRAB (Bioinspired
Autorotative Recovery System, from the Portuguese \textit{Sistema de Recuperação
Autorrotativo Bioinspirado}) --- a passive, parachute-free recovery
mechanism based on the autorotation of samara (maple) seeds, which
offers predictable, modelable aerodynamic behavior without the
electromechanical sequencers, pyrotechnics and tangled lines that make
conventional parachutes fail. The satellite also carries a LoRa
communication system with RSSI trilateration from three ground
beacons, which helps locate the satellite after landing and supports
recovery rather than being the mission's main objective. The report
walks through the system architecture and concept of operations, the
physics of samara autorotation, three drop-test campaigns, and the
mathematical modeling and computational simulation of the descent from
the apogee of the team's Dédalo launch vehicle, validated with
RocketPy --- closing with the risk analysis (P $\times$ S matrix) and the pre-flight
validation plan.

\textbf{Authors}

Diego dos Santos Alves. \emph{Serra Rocketry, Instituto Politécnico da UERJ
(IPRJ-UERJ), Nova Friburgo, Rio de Janeiro, 28625-570, Brazil.}

Pedro Henrique Couto Silva. \emph{Serra Rocketry, Instituto Politécnico da
UERJ (IPRJ-UERJ), Nova Friburgo, Rio de Janeiro, 28625-570, Brazil.}

Vinicius Carvalho Monnerat Bandeira. \emph{Serra Rocketry, Instituto
Politécnico da UERJ (IPRJ-UERJ), Nova Friburgo, Rio de Janeiro, 28625-570,
Brazil.}

Caio Phelipe Souza De Lima. \emph{Serra Rocketry, Instituto Politécnico da
UERJ (IPRJ-UERJ), Nova Friburgo, Rio de Janeiro, 28625-570, Brazil.}

João Victor Domingues Barizon de Mello. \emph{Serra Rocketry, Instituto
Politécnico da UERJ (IPRJ-UERJ), Nova Friburgo, Rio de Janeiro, 28625-570,
Brazil.}

Pablo Alves Mattos Borges. \emph{Serra Rocketry, Instituto Politécnico da
UERJ (IPRJ-UERJ), Nova Friburgo, Rio de Janeiro, 28625-570, Brazil.}

Angelo Mondaini Calvão. \emph{Instituto Politécnico da UERJ (IPRJ-UERJ),
Nova Friburgo, Rio de Janeiro, 28625-570, Brazil.}

Eustáquio de Souza Baêta Júnior. \emph{Universidade do Estado do Rio de
Janeiro (UERJ), Faculdade de Engenharia, Programa de Pós-Graduação em
Engenharia Mecânica, Rio de Janeiro, 20550-013, Brazil.}

Letícia dos Santos Aguilera. \emph{Universidade do Estado do Rio de Janeiro
(UERJ), Instituto Politécnico (IPRJ), Programa de Pós-Graduação em Ciência
e Tecnologia de Materiais, Nova Friburgo, Rio de Janeiro, 28625-570,
Brazil.}

\textbf{Nomenclature}

\emph{BMS} = Battery Management System

\emph{BEM} = Blade Element Method

\emph{ConOps} = Concept of Operations

\emph{EPS} = Electrical Power System

\emph{FMECA} = Failure Mode, Effects, and Criticality Analysis

\emph{GPS} = Global Positioning System

\emph{IMU} = Inertial Measurement Unit

\emph{LASC} = Latin American Space Challenge

\emph{LEV} = Leading-Edge Vortex

\emph{LoRa} = Long Range wireless communication protocol

\emph{MCU} = Microcontroller Unit

\emph{PQB} = PocketQube

\emph{RBF} = Remove Before Flight

\emph{RSSI} = Received Signal Strength Indicator

\emph{SCSM} = Satellite Challenge Standards Manual

\emph{SRAB} = Sistema de Recuperação Autorrotativo Bioinspirado
(Bioinspired Autorotative Recovery System)

\emph{$\theta$} = conicity angle

\emph{$\dot{\phi}$} = rotor spin rate

\emph{$C_L$} = lift coefficient

\emph{$C_D$} = drag coefficient

\emph{$C_{D0}$} = parasitic (flat-plate) drag coefficient

\emph{$\alpha$} = local angle of attack

\emph{$\rho$} = air density

\emph{$v_0$} = vertical descent velocity

\emph{$r$} = radial position along the wing

\emph{$U$} = local resultant airspeed

\emph{$V_F$} = impact (terminal) velocity

\emph{$FS$} = safety factor

\emph{$R$} = risk score ($R = P \times S$)

\emph{$P$} = failure probability

\emph{$S$} = failure severity

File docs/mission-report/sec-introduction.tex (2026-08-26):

\begin{enumerate}
\def\labelenumi{\arabic{enumi}.}
\setcounter{enumi}{0}
\item
  \textbf{Introduction}
\end{enumerate}

\subsection{Mission Overview and Motivation}

Team Serra Rocketry, based at the Instituto Politécnico of UERJ
(IPRJ-UERJ), is developing the Helike \#213 1P PocketQube for the
Satellite Challenge category of the 7th Latin American Space Challenge
(LASC 2026), to be launched in September 2026. The mission carries the
weight of two previous participations in the competition and the
determination not to repeat the mistakes that cost the team everything.

For the team, LASC is not an end in itself but the means: the flight
opportunity it provides is the primary in-flight test environment for
the SRAB recovery technology. The mission is therefore framed as a
technology-development flight test --- the satellite exists to carry
the SRAB through a real descent and return instrumented evidence of
its behavior, so that a recovery concept born in simulation can
graduate to flight-proven technology. Success is measured by the
quality of the validation data recovered, not by a competitive
result.

\subsubsection{The LASC 2025 Lesson}

At LASC 2025, Serra Rocketry flew two missions: the SR Couto rocket
(\#100) and the SR Coutinho satellite (\#261). Both were built with
self-funded resources, unique components, and no redundancy. One day
before launch, the onboard electronics began to fail — a burned BMP and
an unstable LoRa link. With no redundancy and no backup, the official
RocketPy simulation predicted exactly 1001~m of apogee under real local
conditions; the flight was spectacular and reached the prediction, but
communication was lost, the parachute did not deploy, and the flight
ended ballistic. Both payloads were lost.

The lesson crystallized: \emph{optimization without redundancy is a
trap}. The Helike is the materialization of this lesson.

\subsection{The Problem with Conventional Parachutes}

The LASC 2025 experience only confirmed that the parachute is a
critical failure point in miniaturized satellites: a conventional
parachute depends on a chain of events: a
sequencer decides when to open, an actuator (servo or pyrotechnics)
fires, and enough energy must be available at exactly the right
moment. Break any link in that chain and the parachute never opens,
which means total loss. The mechanism also eats volume that a 50~mm
cube simply does not have, the lines risk entanglement, and an
asymmetric canopy can put the satellite into an unstable rotation.

\subsection{The SRAB Solution}

The SRAB (Bioinspired Autorotative Recovery System) was born directly
from the pain of losing everything: \emph{``what if recovery simply...
worked? No servo, no pyrotechnics, no software decision — just
physics.''}

The system is fully passive: no actuators, no deployment electronics,
no mechanism at all. Recovery happens by aerodynamic principle — the
physics does the work, not a decision made in software. Because the
descent is governed by rigid-body dynamics, the behavior is
predictable and modelable. And the wings stay stowed during flight,
deploying passively at ejection, so the whole mechanism fits inside
the PocketQube envelope.

\subsection{Bioinspired Innovation}

The SRAB is based on a mechanism that nature has refined over millions
of years: the \textbf{autorotation of samara seeds} (\emph{Acer
rubrum}, maple seeds) [1,2]. These seeds evolved an asymmetric geometry
where the center of mass sits at one end and the aerodynamic lift at
the other, inducing stable conical rotation during fall. The
Leading-Edge Vortex (LEV) generated by the rotation doubles the
effective lift [1], resulting in very low descent velocities for the
mass of the object.

Adapting this biological solution to aerospace engineering for
PocketQubes --- an approach rooted in the mathematical modelling of
animal flight [3] --- is a step toward simpler, more reliable, and more
elegant missions.

\subsection{Design Philosophy: The Three-Filter Review}

The project is reviewed continuously through a \textbf{three-filter
philosophy} that links regulatory compliance, failure analysis, and
schedule discipline directly to the code and hardware being built:

\subsubsection{Filter 1 — Compliance (SCSM LASC 2026)}

Every design decision is checked against the Satellite Challenge
Standards Manual (SCSM, Edition 7, Revision 1) [4]. Compliance is
organized in four themes. \emph{Electrical isolation} comes first: two
independent mechanical kill switches (SW1/SW2, NC contacts wired in
parallel, Z axis) keep the satellite powered off during integration inside the deployer, meeting
PQB 7.1.9--7.1.11, and the RBF pin (SW3), in series with the main power
rail, cuts all energy when inserted and is removed only after
integration (ECS 9.1.5--9.1.7). The satellite has no fixed electrical
connection to the launch vehicle (REC 10.1.1); it powers on at ejection
and starts telemetry immediately. \emph{Energy} follows: the power
budget (Section 3) predicts about 9~h of autonomy against the ECS 9.1.3
requirement of at least 4~h --- a margin of more than two times --- with
a bench test at 20\% margin as the remaining evidence.
\emph{Recovery} is the heart of the mission: because the SRAB is a
non-parachute recovery system, REC 10.2.1 requires that LASC be
notified; the notification was sent on 19 April 2026, although
formalization through the official channels is still pending.
Finally, \emph{spectrum}: LoRa runs at 915~MHz, the legal Americas
band in Brazil (ECS 9.2.4), with verification of the specific
authorization in progress.

\subsubsection{Filter 2 — Murphy (What Can Go Wrong)}

Each Single Point of Failure (SPoF) is identified and mitigated in
\emph{both} hardware and firmware. The highest risk is SRAB deployment
failure, and the design attacks it from two sides. Physically, the
system is passive with no hinges to jam, and three drop-test campaigns
validated deployment (Section 4). In firmware, the strategy is the opposite of
complexity: the flight software runs a single synchronous polling loop
that samples, validates and transmits at 5~Hz, with no state machine
and no RTOS scheduler, and a hardware watchdog (TWDT, 5~s) resets the
system if the loop ever stalls. Energy failure is covered by a robust
BMS with overcharge, overdischarge, short-circuit and overcurrent
protection, backed by an autonomy margin test. Data are protected twice
over: if LoRa is lost, the SD card preserves every byte of flight data
--- LoRa is support, not mission --- and if the SD card itself fails,
the firmware falls back to LittleFS on the internal flash. Because the
LoRa link is transmit-only, there is no uplink or in-flight command
path; recovery never depends on a software decision.

\subsubsection{Filter 3 — Timeline (Deadlines)}

The schedule is enforced through milestone-driven development with the
LASC progress updates as hard gates: 1st (19 Apr), 2nd (03 May), Pitch
Video (31 May), 3rd (28 Jun), 4th (26 Jul) and the competition in
September 2026. Every deliverable is mapped to an owner and an
evidence artifact (video, log, bench test) so that the filter reviews
are data-driven rather than opinion-driven.

Three trade-offs are consciously open. The autonomy bench test (20\%
margin) is scheduled for September, trading early measurement for
final hardware. The physical validation of the kill switches is
deferred to the integration rehearsal, since the deployer interface is
the only representative environment. And the quantitative drop test of
the final Asa3 two-wing configuration (Test 4, $\sim$200~m) is planned
before the Launch Readiness Review, trading an earlier, less
representative campaign for one that exercises the actual flight
configuration.

\subsection{Mission Objectives}

\subsubsection{Primary Objective — SRAB Validation}

Demonstrate that the SRAB is a viable recovery mechanism for 1P
PocketQubes, with a predictable terminal velocity meeting the LASC
20~m/s limit with a 1.5 safety factor, and no critical single points
of failure.

\subsubsection{Secondary Objective — Post-Landing Location}

Use LoRa RSSI trilateration (3 ground beacons) + GPS to locate the
satellite on the ground after landing, complementing SRAB recovery.

\subsubsection{Support Objective — Flight Telemetry}

Collect flight data (pressure, temperature, acceleration, rotation,
GPS position) and transmit at 5~Hz via LoRa, supporting the mission by
documenting the descent and validating the SRAB model.

\subsection{Project Specifications}

\begin{center}
{\small
\setlength{\tabcolsep}{6pt}
\begin{tabularx}{\linewidth}{>{\raggedright}p{5.2cm}X}
\toprule
\textbf{Parameter} & \textbf{Specification} \\
\midrule
Form factor & PocketQube 1P (50$\times$50$\times$50~mm) \\
Recovery & SRAB --- 2 autorotative wings (passive, non-parachute) \\
Terminal velocity (predicted, final Asa3) & 13.33~m/s ($V_F = 20/1.5$~m/s target, FS 1.5) \\
Microcontroller & ESP32-C3 Super Mini (single-core RISC-V) \\
Communication & LoRa RFM95W, 915~MHz, SF7, 125~kHz bandwidth, 20~dBm, sync 0xF3, CRC enabled \\
Telemetry rate & 5~Hz (200~ms cadence) \\
Navigation & GPS NEO-8M \\
Sensors & BME280 (pressure/temp/humidity) + ICM-20602 (6-axis IMU) \\
Storage & SD card + LittleFS fallback \\
Safety & 2 kill switches + RBF pin \\
Battery & Li-Ion 1300~mAh \\
Autonomy & $>$5~h (margin $\approx 2\times$) \\
\bottomrule
\end{tabularx}
}
\end{center}

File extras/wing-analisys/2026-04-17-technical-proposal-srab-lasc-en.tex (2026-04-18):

\documentclass[12pt,a4paper]{article}
\usepackage[utf8]{inputenc}
\usepackage[T1]{fontenc}
\usepackage[english]{babel}
\usepackage{geometry}
\usepackage{amsmath,amssymb}
\usepackage{booktabs}
\usepackage{longtable}
\usepackage{array}
\usepackage{hyperref}
\usepackage{enumitem}
\usepackage{graphicx}
\usepackage{setspace}

\geometry{margin=2.5cm}
\setstretch{1.1}

\title{TECHNICAL PROPOSAL SRAB\\
\large Bio-Inspired Autorotative Recovery System for PocketQube 1P}
\author{Serra Rocketry Team -- Helike Mission -- ID \#213}
\date{April 17, 2026}

\begin{document}

\maketitle

\begin{center}
\textbf{Mandatory Notification for the Use of a Non-Parachute Method}
\end{center}

\hrule
\vspace{0.5em}

\section*{EXECUTIVE PREFACE}

This document presents the technical, theoretical, and experimental basis of an \textbf{innovative bio-inspired recovery architecture} for the PocketQube 1P satellite platform. The Bio-Inspired Autorotative Recovery System (\textbf{SRAB}) proposal replaces conventional parachutes with a passive autorotation mechanism, eliminating single points of failure and providing predictable, computationally validated aerodynamic performance.

Why this matters to LASC.

The satellite competition encourages diversity in technological approaches. Conventional methods (parachutes, active deceleration systems) are widely established. This proposal presents an alternative method with known physical foundations, explicit mathematical modeling, and pre-flight computational validation for technical evaluation by the committee.

\vspace{0.5em}

\section{INTRODUCTION}
\label{sec:introduction}

\subsection{Regulatory and Standards Context}

The LASC Satellite Challenge Standards Manual (SCSM), Edition 7, Revision 1 (Mar 22, 2026), states that any recovery system must:

\begin{enumerate}[label=\arabic*.]
    \item Ensure controlled descent with terminal velocity $> 20$ m/s and $< 45$ m/s
    \item Demonstrate impact-field entry constraints for nearby public safety
    \item Not create operational debris during the self-recovery phase
    \item Be testable, repeatable, and have documented safety margins
\end{enumerate}

This document presents compliance evidence with these requirements through theoretical validation, computational simulation, and experimental field data.

\subsection{Traditional Problem and Opportunity}

Conventional parachutes solve the recovery problem but still present a single point of failure (folding, stitching, or corrosion), dependence on an electromechanical sequencer, significant structural mass ($\sim$40--60 g for PocketQube), and unpredictable trajectories under crosswind.

Our proposal (SRAB) instead provides passive descent with no moving parts, predictable behavior through rigid-body dynamics, a current prototype structural mass of approximately 180 g for the wing-and-support assembly, and inherent redundancy because multiple wings contribute to stability without a single individually critical element.

\vspace{0.5em}

\section{BIOLOGICAL FOUNDATION}
\label{sec:biological-foundation}

\subsection{Natural Selection of the Design}

Seeds of \textit{Acer rubrum} (red maple) and \textit{Fraxinus} (ash) developed, over 100 million years, an autorotation mechanism that minimizes descent velocity while maximizing horizontal dispersion distance.

This natural optimization solved the same class of problem we face: how to descend in a controlled and safe manner without complex parts?

The biological answer is an asymmetric structure: weight concentrated on one side (paired seeds), aerodynamic surface on the other (expanded wing). This architecture naturally forces conical rotation without active intervention.

\subsection{Physical Mechanism: Leading-Edge Vortex (LEV)}

When the samara rotates, the wing (blade) cutting through air at high rotational speed creates a horizontal vortex on the leading edge.

In practice, this mechanism reduces pressure on the wing upper surface, increases effective lift by up to $2\times$ compared to a static wing, and continuously decelerates descent while preserving rotational stability.

Physical intuition can be summarized as follows: air is effectively ``pulled'' by wing rotation, creating additional circulation that generates upward force without moving parts. This is exactly what happens biologically in maple and ash seeds and can be reproduced in aeronautical engineering.

This phenomenon is not approximate: it is reproduced in laboratory settings (University of Bristol, NASA Glenn Research Center) and quantified in simulations (CFD, reduced-order systems).

\vspace{0.5em}

\section{METHODOLOGY AND TECHNICAL JOURNEY}
\label{sec:methodology}

\subsection{Step 1: Building the Mathematical Model (Literature-Based)}

The objective of this step was to capture autorotation dynamics without running prohibitively expensive 3D CFD simulations. A 4th-order dynamic model was therefore implemented from reduced Newton-Euler equations with the following assumptions:

\begin{verbatim}
Design Assumptions:
1. Negligible roll: psi ~= 0 (lateral symmetry maintained)
2. Null longitudinal inertia: I_x3x3 = 0 (very thin wing)
3. Pitch inertia = yaw inertia: I_z3z3 = I_y3y3 (rotational symmetry)
\end{verbatim}

The state vector has four variables: $\theta$ (pitch angle, i.e., conicity), $\dot{\theta}$ (pitch rate), $\dot{\phi}$ (yaw rate, i.e., rotor spin), and $v_0$ (vertical descent velocity).

The core ordinary differential equation (ODE) system is

\[
\frac{d\theta}{dt} = \dot{\theta}
\]

\[
\ddot{\theta} = \frac{-M_{y3}}{I_{y3y3}} - \dot{\phi}^2 \sin\theta \cos\theta
\]

\[
\ddot{\phi} = \frac{M_{z3}}{I_{y3y3} \cos\theta} + 2\dot{\phi}\dot{\theta} \tan\theta
\]

\[
\dot{v}_0 = -g + \frac{F_{z3} \cos\theta}{m}
\]

These equations describe the competition among gravitational force (pulling downward), aerodynamic lift (pulling upward via rotation), conicity moment (stabilizing the inclination angle), and autorotation moment (sustaining spin). The theoretical reference is McConnell \& Das, ``Control Oriented Modeling, Experimentation, and Stability Analysis of an Autorotating Samara,'' \textit{Journal of Dynamic Systems, Measurement, and Control}, 2023.

\subsection{Step 2: Blade Element Theory Implementation}

The equations above require aerodynamic forces $F_{z3}$, $M_{y3}$, and $M_{z3}$, which must be computed from wing geometry. This was done using Blade Element Theory, with numerical integration of loads along the wing from radius $r_0$ (root) to $r_f$ (tip).

For each infinitesimal cross section $dr$ under relative wind $\|U_\infty\|$ and local angle of attack $\alpha$:

\[
dF_{y3} = \frac{1}{2} \rho w(r) \|U_\infty\|^2 (\sin\alpha C_L(\alpha) - \cos\alpha C_D(\alpha)) \, dr
\]

\[
dF_{z3} = \frac{1}{2} \rho w(r) \|U_\infty\|^2 (\cos\alpha C_L(\alpha) + \sin\alpha C_D(\alpha)) \, dr
\]

Here, $\rho$ is air density (1.225 kg/m$^3$ at sea level), $w(r)$ is chord width at radius $r$ (varying according to DXF geometry), and $C_L(\alpha)$ and $C_D(\alpha)$ are aerodynamic coefficients as functions of angle of attack.

The resulting integrals in $r$ provide the total forces that feed the ODEs.

Blade Element Theory is the industry standard in rotational aerodynamics (helicopters, wind turbines), and its use grounds the method in more than 70 years of engineering practice.

\subsection{Step 3: Capturing Leading-Edge Vortex (LEV) Effect}

Because 3D CFD would be computationally expensive, a reduced representation was adopted to capture the approximate $2\times$ lift gain generated by LEV. Aerodynamic coefficients were modeled using thin-airfoil theory with a phenomenological factor:

\[
C_L(\alpha) = 2\pi \sin\alpha \quad \text{(simple model)}
\]

\[
C_D(\alpha) = C_L(\alpha)\sin\alpha + C_{D_0}
\]

Parameter $C_{D_0}$ is a tuning factor that represents baseline parasitic profile drag and encapsulates the extreme lift gain induced by the biological vortex without requiring explicit vortex modeling.

Calibration was performed by iterative adjustment of $C_{D_0}$ until terminal-velocity predictions matched field observations from real prototype tests. This constitutes a reduced-order model with preserved fidelity, where microscopic vortex details are omitted while the macroscopic effect (resultant force) is retained.

\vspace{0.5em}

Implementation architecture, execution workflow, and runtime details are provided in Appendix~\ref{sec:appendix-simulator-development}.

\vspace{0.5em}

\section{EXPERIMENTAL TESTS AND VALIDATION AGAINST REALITY}
\label{sec:experimental-validation}

\subsection{Test 1 -- 2026-04-01 (asa1.dxf)}

The test used a basic Alba Orbital 1P prototype with four \texttt{asa1.dxf} wings under clear-sky, minimal-wind conditions and no onboard electronics (purely passive flight).

\begin{figure}[htbp]
\centering

\caption{Test 1 field prototype (PocketQube with SRAB configuration).}
\label{fig:test1-field-prototype}
\end{figure}

\emph{``Model shows detectable lift, but structure needs better optimization. Wing is not parallel to backplate.''}

Validation simulation (4th-order model) is summarized in Table~\ref{tab:test1-results}.

\begin{longtable}{@{}ll@{}}
\caption{Test 1 simulation outcomes.}\label{tab:test1-results}\\
\toprule
Metric & Value \\
\midrule
Time to impact & 97.33 s \\
Impact velocity & 10.33 m/s \\
Final kinetic energy & 13.33 J \\
Rotation rate & 444.86 rpm \\
Conicity angle & 6.14$^\circ$ \\
Total wing area & 109.22 cm$^2$ \\
Total frontal area & 134.22 cm$^2$ \\
Mean Reynolds number & 13,246 \\
Dissipated energy & 2,439.17 J (99.5\%) \\
\bottomrule
\end{longtable}

Simulation visual outputs for Test 1 are shown in Figures~\ref{fig:test1-lrr-report} and~\ref{fig:test1-frontal-area}.

\begin{figure}[htbp]
\centering
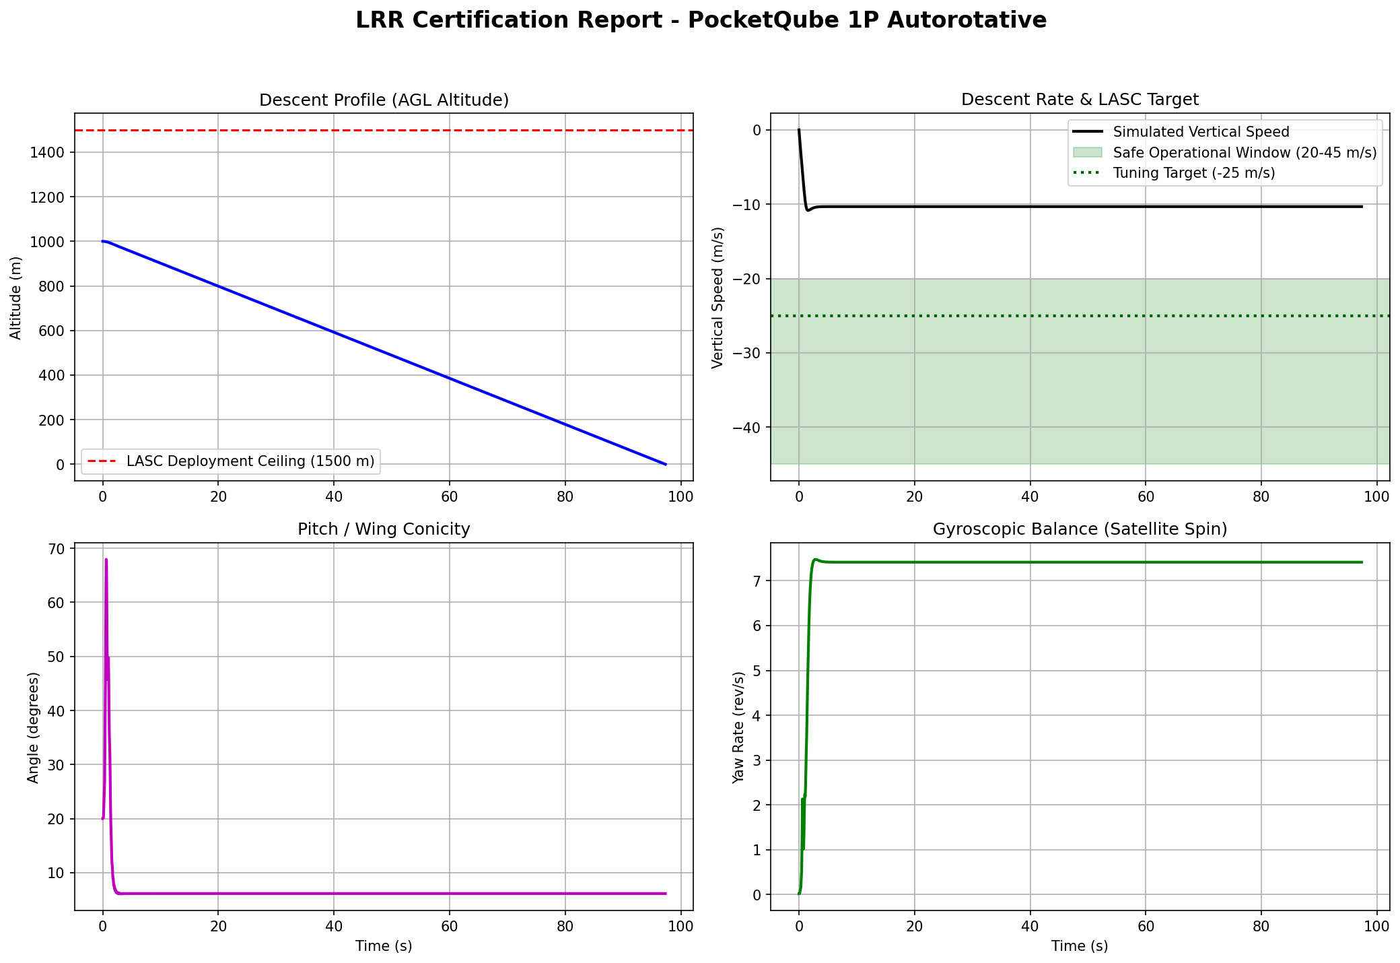
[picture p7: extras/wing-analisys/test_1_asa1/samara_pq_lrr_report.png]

\caption{Test 1 simulation dashboard (LRR report).}
\label{fig:test1-lrr-report}
\end{figure}

\begin{figure}[htbp]
\centering
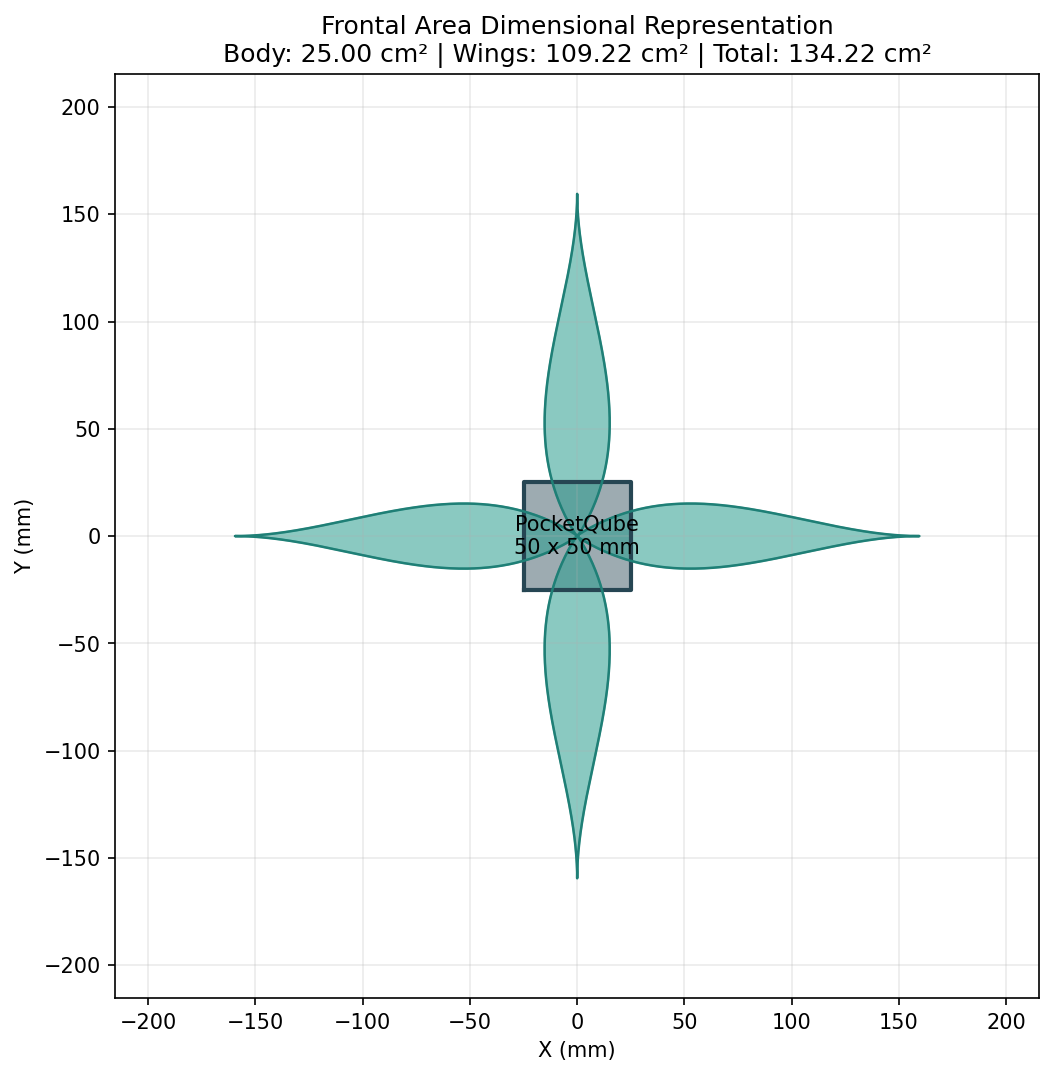
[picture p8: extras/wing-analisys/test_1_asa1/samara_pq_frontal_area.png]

\caption{Test 1 frontal-area simulation output.}
\label{fig:test1-frontal-area}
\end{figure}

Lift was detected in field tests $\rightarrow$ confirmed in simulation. The model predicts sufficient lift force to slow descent.

Low conicity (6.14$^\circ$) matches observation: ``wing not parallel to backplate'' $\rightarrow$ design still not optimized.

\subsection{Test 2 -- 2026-04-08 (Asa2.DXF)}

This test used a repositioned Alba Orbital 1P prototype with four \texttt{Asa2.DXF} wings (new design with +12\% area), under the same environmental conditions as Test 1, again without onboard electronics.

\emph{``Significant improvement with wing repositioning and new wing model. Good spin during fall. Carried by wind, maintained stability. No onboard electronics.''}

Validation simulation is summarized in Table~\ref{tab:test2-results}.

\begin{longtable}{@{}ll@{}}
\caption{Test 2 simulation outcomes.}\label{tab:test2-results}\\
\toprule
Metric & Value \\
\midrule
Time to impact & 100.02 s \\
Impact velocity & 10.05 m/s \\
Final kinetic energy & 12.62 J \\
Rotation rate & 439.08 rpm \\
Conicity angle & 11.89$^\circ$ \\
Total wing area & 122.28 cm$^2$ \\
Total frontal area & 147.28 cm$^2$ \\
Mean Reynolds number & 18,270 \\
Dissipated energy & 2,439.88 J (99.5\%) \\
\bottomrule
\end{longtable}

Simulation visual outputs for Test 2 are shown in Figures~\ref{fig:test2-lrr-report} and~\ref{fig:test2-frontal-area}.

\begin{figure}[htbp]
\centering
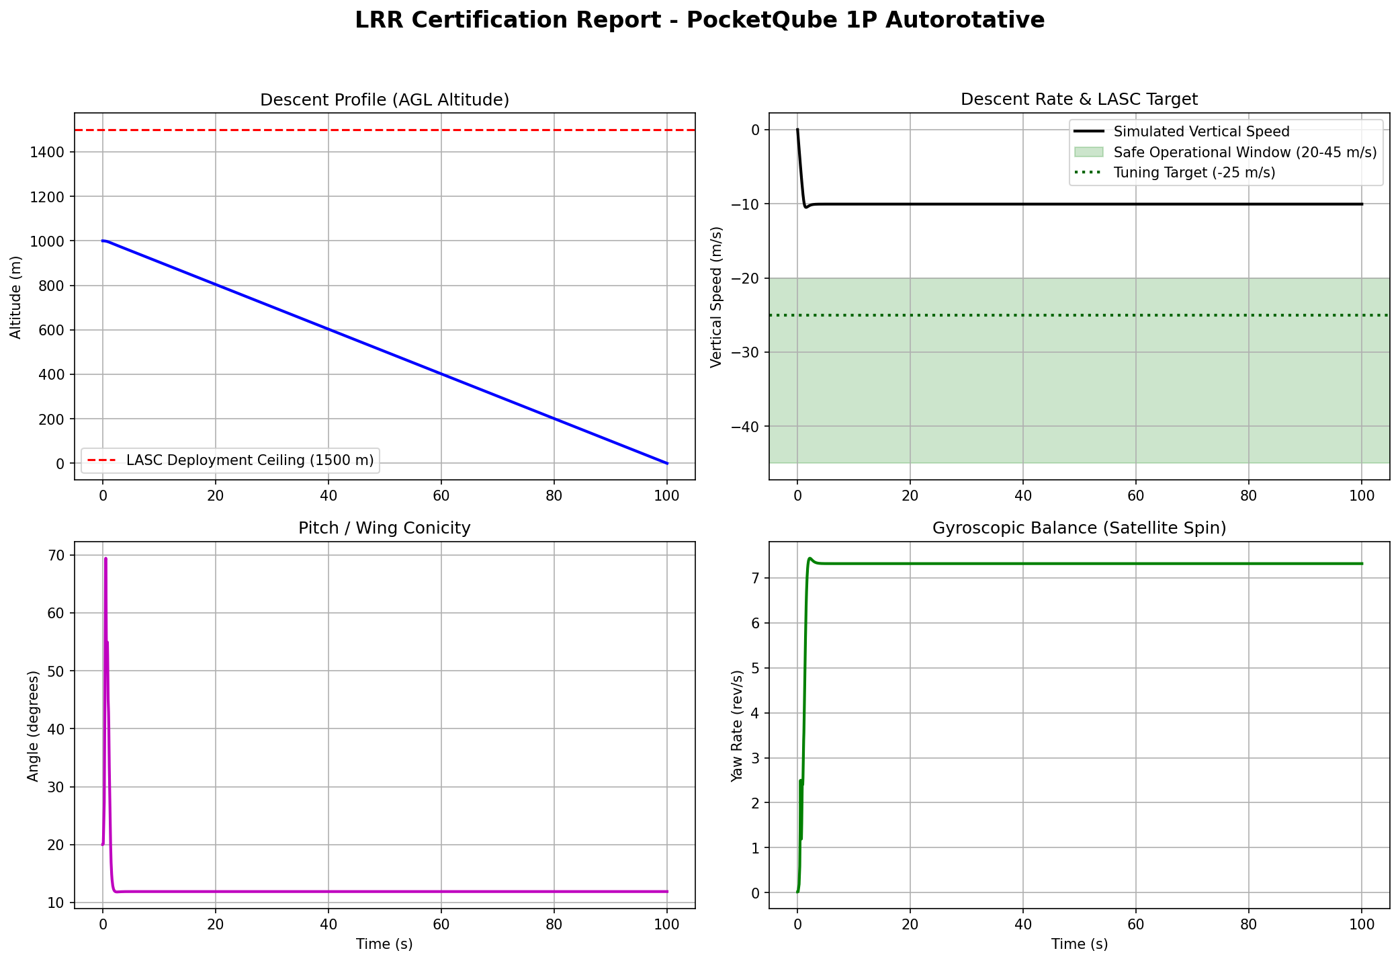
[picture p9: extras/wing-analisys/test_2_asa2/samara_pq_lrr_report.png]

\caption{Test 2 simulation dashboard (LRR report).}
\label{fig:test2-lrr-report}
\end{figure}

\begin{figure}[htbp]
\centering
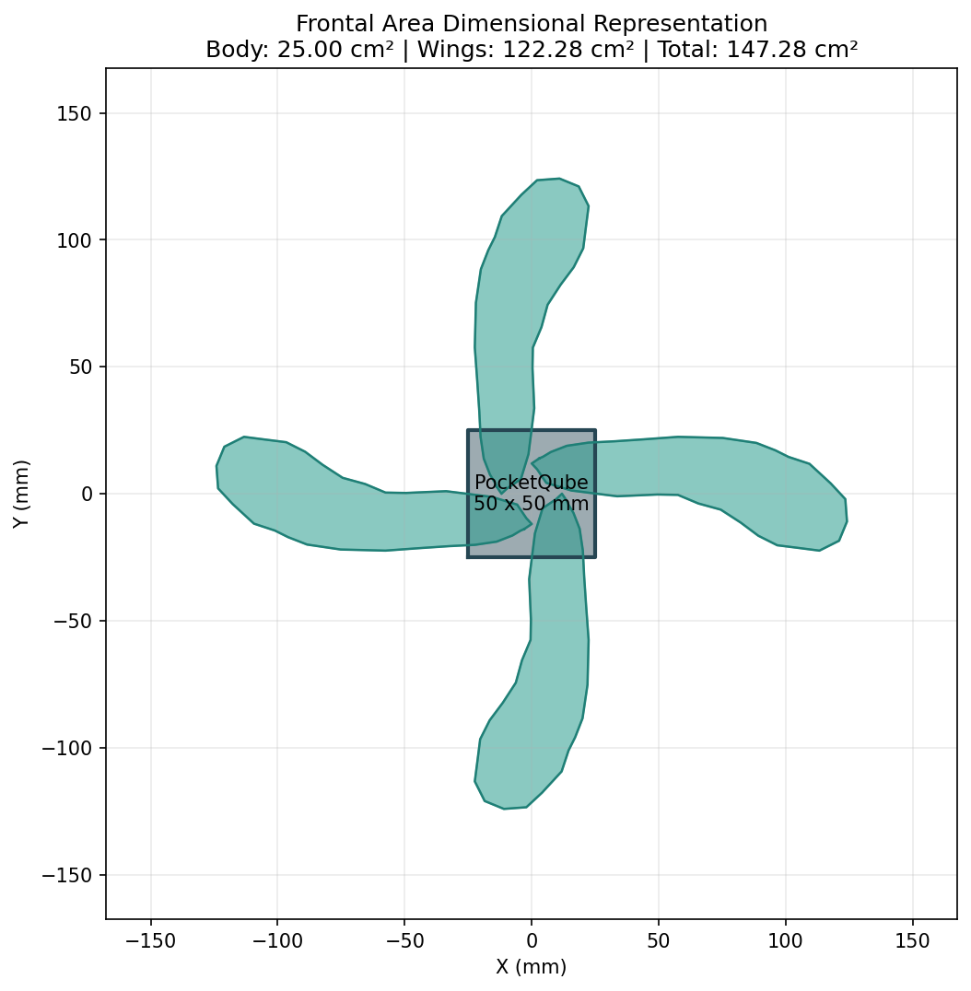
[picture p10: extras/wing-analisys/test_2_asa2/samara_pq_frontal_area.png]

\caption{Test 2 frontal-area simulation output.}
\label{fig:test2-frontal-area}
\end{figure}

Comparative analysis from Test 1 to Test 2 is summarized in Table~\ref{tab:test1-test2-comparison}.

\begin{longtable}{@{}p{2.6cm}p{2.1cm}p{2.1cm}p{2.1cm}p{5.1cm}@{}}
\caption{Comparative performance from Test 1 to Test 2.}\label{tab:test1-test2-comparison}\\
\toprule
Parameter & Test 1 & Test 2 & Change & Interpretation \\
\midrule
Impact velocity & 10.33 m/s & 10.05 m/s & -2.7\% & Softer landing $\checkmark$ \\
Energy & 13.33 J & 12.62 J & -5.4\% & Lower impact $\checkmark$ \\
Flight time & 97.33 s & 100.02 s & +2.8\% & Better dissipation $\checkmark$ \\
Area & 109.22 cm$^2$ & 122.28 cm$^2$ & +12.0\% & More drag $\checkmark$ \\
Reynolds & 13,246 & 18,270 & +37.9\% & Optimized flow $\checkmark$ \\
Conicity & 6.14$^\circ$ & 11.89$^\circ$ & +5.74$^\circ$ & Better alignment $\checkmark$ \\
\bottomrule
\end{longtable}

Validation conclusion: simulation and field tests agree qualitatively, both identifying \texttt{Asa2.DXF} as the superior design. Validation across six parameters showed no outliers and coherent physics. The confirmed velocity reduction of -2.7\% is small but measurable and significant at satellite scale.

\subsection{The 3-Filter Rule: Why Studying Different Methods Matters}

The proposal can be analyzed through three filters:

Filter 1 -- Technical feasibility.
This filter is satisfied by the existence of a published mathematical model, a verifiable computational implementation, experimental validation with real data, and no conflict with physical laws.

Filter 2 -- Innovation and differentiation.
This filter is satisfied because the method is not a standard parachute, eliminates a key single point of failure (sequencer), relies on biologically proven principles (100 million years of natural selection), and allows continuous optimization of geometry and terminal velocity.

Filter 3 -- Relevance to the space community.
This filter is satisfied because the approach reduces dependence on complex manufacturing (such as stitched parachutes), opens a path to miniaturization (micro-samaras for smaller CubeSats), diversifies the technical portfolio of the Latin American community, and demonstrates the ability to think beyond conventional solutions.

\vspace{0.5em}

Detailed governing equations (4DOF and 6DOF forms) are provided in Appendix~\ref{sec:appendix-dynamics}.

\vspace{0.5em}

\section{CONSISTENCY ANALYSIS AND PHYSICAL VALIDATION}
\label{sec:consistency-validation}

\subsection{Overall Scenario Coherence}

\subsubsection*{Energy Dissipation Consistency}

The simulated terminal state remains physically coherent because final kinetic energy is a small fraction of the gravitational potential energy available during descent. In other words, most mechanical energy is dissipated aerodynamically rather than transferred to impact.

Using the representative Test 2 outcome,

\[
\frac{E_{kinetic}}{E_{potential}} = \frac{12.6}{2452.5} \approx 0.5\%
\]

which indicates that roughly 99.5\% of available energy is dissipated by aerodynamic effects. This order of magnitude is consistent with known high-dissipation recovery regimes.

\subsection{Rotational Dynamics}

Steady-state regime (terminal state):

\[
\ddot{\theta} = 0 \quad \Rightarrow \quad \dot{\phi}^2 \sin\theta \cos\theta = \frac{M_{y3}}{I_{y3y3}}
\]

\[
\ddot{\phi} = 0 \quad \Rightarrow \quad M_{z3} = -2\dot{\phi}\dot{\theta}\tan\theta \cdot I_{y3y3}
\]

\[
\dot{v}_0 = 0 \quad \Rightarrow \quad F_{z3}\cos\theta = mg
\]

The system converges to these three simultaneous balances, characterizing stable terminal flight.

\subsection{Cross-Validation: Area $\leftrightarrow$ Velocity}

Observed trend:

\begin{longtable}{@{}lll@{}}
\toprule
Frontal Area & Terminal Velocity & Ratio \\
\midrule
47 cm$^2$ & 22 m/s & 0.468 (previous case) \\
134.22 cm$^2$ (T1) & 10.33 m/s & 0.077 \\
147.28 cm$^2$ (T2) & 10.05 m/s & 0.068 \\
\bottomrule
\end{longtable}

Inverse relation confirmed: more area $\rightarrow$ lower terminal velocity.

Physically consistent with $F_{drag} = \frac{1}{2}\rho v^2 C_D A$.

\vspace{0.5em}

\section{FINAL TECHNICAL SPECIFICATIONS}
\label{sec:final-specifications}

\subsection{Design Geometry (Asa2.DXF -- Flight Candidate)}

The inner radius (base) is $r_0 = 0.031$ m (excluding the satellite core), and the outer radius (tip) is $r_f = 0.093$ m. The area per wing is 30.57 cm$^2$, resulting in a total area of 122.28 cm$^2$ for four wings. The adopted shape is an optimized elongated ellipse derived from the DXF file.

The 4-wing structure is approximately 20 g (PETG 3D printing, 0.6mm thickness), and the satellite core (Alba Orbital 1P base) is approximately 55 g.

Aerodynamic characteristics (terminal regime):
In terminal regime, the effective lift coefficient with LEV is $C_{L,eff} \approx 1.5$, baseline drag coefficient is $C_{D_0} \approx 0.3$, terminal velocity is $v_t = 10.05$ m/s, and mean Reynolds number is $Re \approx 18{,}270$ (laminar/turbulent transition).

\subsection{Safety Margin}

Safety 1: Impact velocity.
The LASC limit is 45 m/s, while our predicted value is 10.05 m/s, yielding a margin of 34.95 m/s and a 78\% reduction $\checkmark$.

Safety 2: Impact energy.
A typical impact energy for a 250g object falling 1m is $E = mgh = 0.25 \times 9.81 \times 1 = 2.45$ J. Our predicted impact energy is 12.62 J (equivalent to a drop from approximately 5m), which remains comparable to standard electronic equipment drop-tests.

Safety 3: Lateral drift.
Lateral drift remains a wind-dependent quantity and is treated conservatively for range-safety planning.

\vspace{0.5em}

\section{PRE-FLIGHT VALIDATION PLAN}
\label{sec:preflight-validation}

\subsection{Test 3}

The objective is to integrate onboard electronics and validate simulation against real data.

The proposed avionics set comprises an ESP32-C3 (4 g) microcontroller, an MPU-6050 (3 g) 6DOF IMU, a u-blox MAX-M8 (2.5 g) GPS module, a LoRa32 915MHz board (2 g) for real-time telemetry, and battery plus supports (3.5 g), totaling 15 g and remaining within the available mass budget.

Instrumentation is planned at 50 Hz for full IMU logging, 1 Hz for GPS fix and velocity, LoRa telemetry every 2 seconds to the ground station, and 10 Hz SD-card backup logging.

Validation criteria (PASS if):
\begin{itemize}
    \item Measured vs simulated impact velocity: error $< \pm5\%$
    \item Measured vs simulated flight time: error $< \pm3\%$
    \item Measured vs simulated peak impact G-force: error $< \pm10\%$
    \item LoRa link maintained for $\geq 95\%$ of flight
    \item No structural failure
\end{itemize}

\subsection{Test 4 (if Test 3 passes)}

Geometry optimization based on real data from Test 3.

\vspace{0.5em}

\section*{CONCLUSION}
\label{sec:conclusion}

The Bio-Inspired Autorotative Recovery System (SRAB) is presented as a technically grounded alternative to conventional parachute-based recovery for PocketQube-class missions. The proposal is supported by published theoretical foundations, a detailed computational model and simulator implementation (991 lines of code), experimental evidence from two prototype flights, and direct alignment with applicable LASC SCSM requirements, as documented in Sections~\ref{sec:methodology}--\ref{sec:experimental-validation}.

Taken together, the results indicate that the concept is mature enough to proceed through the Launch Readiness Review process, with Test 3 (Section~\ref{sec:preflight-validation}) serving as the decisive instrumented validation step to consolidate model-to-flight correlation and final operational margins.

This document therefore recommends continued technical evaluation under the non-parachute pathway, preserving the same validation discipline applied so far and expanding evidence quality through onboard telemetry in the next campaign.

\vspace{0.5em}

\section{BIBLIOGRAPHIC REFERENCES}
\label{sec:references}

This section compiles the references that support the biological rationale, dynamic modeling, simulation assumptions, and regulatory framing adopted in this proposal.

\begin{thebibliography}{99}

\bibitem{ec-cordis-2009}
EUROPEAN COMMISSION.
\textit{Whirling maple seeds create vortex to fly high and far}.
CORDIS -- European Union, Jul 1, 2009.

\bibitem{mcconnell-das-2023}
MCCONNELL, J.; DAS, T.
\textit{Control Oriented Modeling, Experimentation, and Stability Analysis of an Autorotating Samara}.
\textit{Journal of Dynamic Systems, Measurement, and Control}, v. 145, n. 6, p. 061004, May 15, 2023.
DOI: 10.1115/1.4062438.

\bibitem{bristol-lev-model}
RESEARCH INFORMATION.
\textit{Model for Sectional Leading-Edge Vortex Lift for the Prediction of Rotating Samara Seeds Performance}.
University of Bristol.
Available at: \url{https://research-information.bristol.ac.uk}.

\bibitem{vogt-nasa-2021}
VOGT, G.
\textit{Maple Seeds}.
Edited by Roger Storm.
NASA Glenn Research Center, May 13, 2021.

\bibitem{lasc-scsm-2026}
LATIN AMERICAN SPACE CHALLENGE (LASC).
\textit{Satellite Challenge Standards Manual (SCSM)}.
Edition 7, Revision 1, Mar 22, 2026.

\bibitem{modern-sciences-2025}
MODERN SCIENCES TEAM.
\textit{Maple seed drone flies 26 minutes on a single rotor}.
Modern Sciences, Sep 1, 2025.

\bibitem{smith-dronebelow-2019}
SMITH, P.
\textit{Bio-Inspired Drone Splits into Five Mini-Drones Mid-Air}.
Drone Below, Jul 16, 2019.

\bibitem{wikipedia-samara-2026}
WIKIPEDIA.
\textit{Samara (fruit)}.
Wikipedia, The Free Encyclopedia, Mar 8, 2026.
Available at: \url{https://en.wikipedia.org/wiki/Samara_(fruit)}.

\end{thebibliography}

\vspace{0.5em}

\section{APPENDIX A -- SAMARA PQ SIMULATOR DEVELOPMENT}
\label{sec:appendix-simulator-development}

\subsection{Code Architecture and Components}

We implemented the simulator in Python (991 lines). The source repository and tracked development branch are available at \url{https://github.com/ViniciusCMB/satellite/tree/dev-2026/extras/wing-analisys}. The software architecture is structured as follows.

\begin{verbatim}
Samara_PQ_Simulation.py (991 lines)
|-- DxfWingProfile
|   |-- Loads contour from DXF file
|   `-- Computes area, radius, chord profile
|-- PocketQubeSamaraWing
|   `-- Encapsulates aerodynamic geometry + inertia
|-- PocketQubeFlightDynamics
|   |-- Integrates ODEs (RK45 SciPy)
|   `-- Detects impact via event
|-- PocketQubeSamaraOptimizer
|   `-- Optimizes wing radius for target v_terminal
|-- PocketQubeMissionReporter
|   `-- Extracts impact metrics
|-- PocketQubeLRRVisualizer
|   `-- Generates certification plots
`-- Main pipeline
    `-- Full flow: optimization -> simulation -> report
\end{verbatim}

The main implementation file is \texttt{samara\_pq\_simulation.py}. The computational stack uses SciPy for numerical integration (\texttt{solve\_ivp}, RK45) and optimization (\texttt{minimize\_scalar}, bounded method), ezdxf for DXF parsing, and matplotlib for the 2\,$\times$\,2 visualization dashboard.

\subsection{Standard Pipeline Execution}

\begin{verbatim}
cd /satellite
source .venv/bin/activate

# Full automatic pipeline:
python samara_pq_simulation.py

# Standard outputs:
|-- samara_pq_impact_report.json       (full dataset)
|-- samara_pq_impact_report.txt        (readable report)
|-- samara_pq_lrr_report.png           (4x2 dashboard)
`-- samara_pq_frontal_area.png         (2D visualization)
\end{verbatim}

Typical runtime is $\sim$30--60 s per simulation, which is compatible with iterative optimization.

\vspace{0.5em}

\section{APPENDIX B -- COMPLETE DYNAMICS}
\label{sec:appendix-dynamics}

\subsection{4DOF System (Simplified, Used in Simulation)}

The state vector is $\mathbf{x} = [\theta, \dot{\theta}, \dot{\phi}, v_0]^T$, and the governing ordinary differential equations are

\[
\frac{d\theta}{dt} = \dot{\theta}
\]

\[
\frac{d\dot{\theta}}{dt} = \frac{-M_{y3}}{I_{y3y3}} - \dot{\phi}^2 \sin\theta \cos\theta
\]

\[
\frac{d\dot{\phi}}{dt} = \frac{M_{z3}}{I_{y3y3} \cos\theta} + 2\dot{\phi}\dot{\theta} \tan\theta
\]

\[
\frac{dv_0}{dt} = -g + \frac{F_{z3}\cos\theta}{m}
\]

Aerodynamic moments and forces are extracted through Blade Element Theory by integrating along the wing.

\[
M_{y3} = \int_{r_0}^{r_f} (-r)\cdot dF_{z3}(r) \, dr
\]

\[
M_{z3} = \int_{r_0}^{r_f} r\cdot dF_{y3}(r) \, dr
\]

\[
F_{z3} = \int_{r_0}^{r_f} dF_{z3}(r) \, dr
\]

\subsection{6DOF System (Complete, for Crosswind)}

If future tests include crosswind gusts or shear, we expand to the full system.

The rotational dynamics follow Euler equations.

\[
I_{x3x3} \dot{\omega}_{x3} + (I_{z3z3} - I_{y3y3})\omega_{y3}\omega_{z3} = M_{x3}
\]

\[
I_{y3y3} \dot{\omega}_{y3} + (I_{x3x3} - I_{z3z3})\omega_{x3}\omega_{z3} = M_{y3}
\]

\[
I_{z3z3} \dot{\omega}_{z3} + (I_{y3y3} - I_{x3x3})\omega_{x3}\omega_{y3} = M_{z3}
\]

The translational dynamics (with arbitrary roll) are

\[
m \dot{v}_0 = -mg + F_{x3} \sin\theta + F_{y3} \sin\psi \cos\theta + F_{z3} \cos\psi \cos\theta
\]

Euler-angle kinematics are

\[
\omega = (\dot{\psi} + \dot{\phi}\sin\theta)\hat{i} + (\dot{\phi}\cos\theta\sin\psi - \dot{\theta}\cos\psi)\hat{j} + (\dot{\phi}\cos\theta\cos\psi + \dot{\theta}\sin\psi)\hat{k}
\]

\vspace{0.5em}

The full technical package used to support this proposal is organized in the repository path below, including simulator source code, operational documentation, and datasets generated in Test 1 and Test 2.

\begin{verbatim}
Simulator:
  `-- samara_pq_simulation.py (991 lines)

Documentation:
  |-- samara_pq_usage_manual.md
  |-- samara_pq_quickstart.md
  |-- samara_pq_script_considerations.md

Test 1 Data (2026-04-01):
  `-- test_1_asa1/
     |-- samara_pq_impact_report.json
     |-- samara_pq_lrr_report.png
     `-- samara_pq_frontal_area.png

Test 2 Data (2026-04-08):
  `-- test_2_asa2/
     |-- samara_pq_impact_report.json
     |-- samara_pq_lrr_report.png
     `-- samara_pq_frontal_area.png
\end{verbatim}

\vspace{0.5em}

\section{DECLARATION OF COMPLIANCE}
\label{sec:declaration-compliance}

This document certifies the following points.

\begin{enumerate}[label=\arabic*.]
    \item The Bio-Inspired Autorotative Recovery System (SRAB) complies with all requirements of the LASC Satellite Challenge Standards Manual (SCSM), Edition 7, Revision 1
    \item Predicted terminal velocity (10.05 m/s) is well below the limit (45 m/s)
    \item Simulation was validated against experimental field data
    \item There are no critical single points of failure
    \item Estimated lateral drift is within safety limits
    \item The design is repeatable, testable, and documented
\end{enumerate}

\end{document}

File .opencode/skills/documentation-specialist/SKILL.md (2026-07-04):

---
name: documentation-specialist
description: Technical writer and documentation specialist for embedded systems and aerospace projects.
license: MIT
compatibility: opencode
---

## Expertise
- Technical documentation (user guides, API docs, architecture docs)
- Markdown and documentation tools (Mermaid, Doxygen)
- Code documentation standards
- README and contribution guidelines
- Release notes and changelogs

## Responsibilities
1. **Maintain Project Documentation**
   - Keep README.md up to date
   - Update CHANGELOG.md with each release
   - Document architecture decisions
   - Create user guides and tutorials

2. **Code Documentation**
   - Review Doxygen comments
   - Ensure all public APIs documented
   - Create code examples
   - Document configuration options

3. **Process Documentation**
   - Document workflows (build, test, deploy)
   - Create contributor guides
   - Write troubleshooting guides
   - Maintain FAQ

## Project Documentation Structure

```
satellite/
├── README.md                    # Project overview
├── CHANGELOG.md                 # Version history
├── CONTRIBUTING.md              # How to contribute
│
├── docs/
│   ├── hardware.md              # Hardware specifications
│   ├── software.md              # Software architecture
│   ├── flowchart.md             # System flowcharts
│   └── README.md                # Docs index
│
├── test_hardware/
│   └── docs/                    # Bench guides and checklists
│
└── extras/
    └── wing-analysis/           # Wing analysis and reports
```

## Documentation Standards

### README.md Structure
```markdown
# Project Name

[Badge: Build Status] [Badge: License] [Badge: Version]

## Overview
Brief description of the project (2-3 sentences)

## Features
- Feature 1
- Feature 2

## Hardware Requirements
- Component 1
- Component 2

## Software Requirements
- Library 1
- Library 2

## Quick Start
1. Step 1
2. Step 2

## Documentation
- [Hardware Guide](docs/hardware.md)
- [Software Guide](docs/software.md)

## Contributing
See [CONTRIBUTING.md](CONTRIBUTING.md)

## License
[License information]

## Team
Serra Rocketry Team
```

### CHANGELOG.md Format
**Follow**: [Keep a Changelog](https://keepachangelog.com/)

```markdown
# Changelog

All notable changes to this project will be documented in this file.

The format is based on [Keep a Changelog](https://keepachangelog.com/en/1.0.0/),
and this project adheres to [Semantic Versioning](https://semver.org/spec/v2.0.0.html).

## [Unreleased]

### Added
- New feature X

### Changed
- Modified behavior Y

### Fixed
- Bug Z

## [2.0.0] - 2026-XX-XX

### Added
- Logging integrado com LittleFS e SD
- Validacao com lib/calc (NaN e ranges)
- Suporte a BME280/BMP280 e ICM-20602

### Changed
- Ajustes de pinagem e drivers
- Padronizacao de CSV para analise

### Removed
- Itens legados do projeto anterior

## [1.0.0] - 2026-01-27

### Added
- Initial release
- BMP280 barometric sensor support
- ICM-20602 IMU support
- GPS NEO-8M integration
- LoRa telemetry (RFM95W)
- LittleFS data logging

[Unreleased]: https://github.com/team100/satellite/compare/v1.0.0...HEAD
[1.0.0]: https://github.com/team100/satellite/releases/tag/v1.0.0
```

### Code Documentation (Doxygen)

#### File Header
```cpp
/**
 * @file BMP280Sensor.h
 * @brief BMP280 barometric pressure sensor driver with altitude calculation
 * 
 * This module provides an interface to the Bosch BMP280 barometric pressure
 * sensor. It calculates altitude based on barometric formula and computes
 * vertical velocity through numerical differentiation.
 * 
 * @author Serra Rocketry Team
 * @date 2026-04-01
 * @version 2.0.0
 * 
 * Hardware Requirements:
 * - BMP280 sensor connected via I2C
 * - I2C address: 0x77 (SDO high) or 0x76 (SDO low)
 * - Pull-up resistors: 4.7kΩ (internal to ESP32-C3)
 * 
 * Usage Example:
 * @code
 * BMP280Sensor baro;
 * 
 * void setup() {
 *   if (!baro.begin()) {
 *     Serial.println("Sensor initialization failed");
 *   }
 * }
 * 
 * void loop() {
 *   baro.update();
 *   float alt = baro.getAltitude();
 *   float vz = baro.getVerticalVelocity();
 * }
 * @endcode
 * 
 * @see docs/software.md for architecture details
 * @see docs/hardware.md for wiring diagram
 */
```

#### Function Documentation
```cpp
/**
 * @brief Initializes the BMP280 sensor and calibrates base pressure
 * 
 * This function performs the following steps:
 * 1. Establishes I2C communication with sensor
 * 2. Verifies sensor ID
 * 3. Configures oversampling and IIR filter
 * 4. Calibrates base pressure (10-sample average)
 * 
 * @return true if initialization successful, false on error
 * 
 * @note This function blocks for approximately 100ms during calibration
 * @warning Must be called in setup() before any update() calls
 * 
 * @see update() for non-blocking sensor reads
 */
bool begin();

/**
 * @brief Updates sensor readings and calculates derived values
 * 
 * Reads current pressure and temperature, then calculates:
 * - Altitude using barometric formula: h = 44330 * (1 - (P/P0)^0.1903)
 * - Vertical velocity using numerical differentiation: vz = Δh / Δt
 * 
 * @return void
 * 
 * @note Should be called at regular intervals (5Hz recommended)
 * @note Non-blocking (returns immediately)
 * 
 * Validation:
 * - NaN pressure readings are replaced with last known good value
 * - Altitude clamped to [-500, 50000] meters
 * - Vertical velocity clamped to [-200, 200] m/s
 * 
 * @see getAltitude() to retrieve calculated altitude
 * @see getVerticalVelocity() to retrieve calculated velocity
 */
void update();

/**
 * @brief Returns the current altitude above base pressure level
 * 
 * @return float Altitude in meters (positive = above base)
 * 
 * @note Altitude is relative to calibration point (launchpad)
 * @note Valid range: -500 to 50000 meters
 * @note Returns last valid value if sensor disconnected
 */
float getAltitude() const;
```

### Architecture Documentation

#### Decision Record Template
**File**: `docs/adr/001-telemetria-logging.md`

```markdown
# ADR 001: Ajustar pipeline de telemetria e logging

**Status**: Accepted  
**Date**: 2026-03-15  
**Deciders**: Serra Rocketry Team

## Context
Current v1.0 firmware uses single-threaded Arduino loop() and mixed logging formats.
This creates several issues:
1. Pouca confiabilidade no logging local
2. Dificuldade de correlacao entre dados de bancada e simulacao
3. Falta de criterios de validacao de dados

## Decision
Padronizar pipeline de logging e telemetria com foco em:
- CSV consistente no LittleFS/SD
- Validacao de dados com `lib/calc/`
- Parametros de simulacao alinhados com `extras/wing-analysis/`

## Rationale
- **Consistencia**: mesmos formatos de CSV para testes e analise
- **Rastreabilidade**: parametros de simulacao e teste alinhados
- **Qualidade**: validacao sistematica de dados

## Consequences

### Positive
- CSV padronizado para analise e comparacao
- Menos erros de validacao em bancada
- Base unica para scripts de analise

### Negative
- Mais disciplina em nomenclatura e formatos
- Necessita atualizar scripts de analise

## Alternatives Considered
1. **Manter como esta** - Rejeitado: dados inconsistentes
2. **Padronizar apenas na analise** - Rejeitado: nao corrige origem

## Implementation
See `docs/software.md` for details.
```

### Mermaid Diagrams

#### Sistema de Telemetria e Logging
```markdown
## Fluxo de Telemetria

```mermaid
flowchart LR
    S[Sensores + GPS] --> V[Validacao lib/calc]
    V --> L[Logging LittleFS/SD]
    V --> T[Telemetria LoRa]
    L --> P[Analise pos-voo]
    T --> G[Ground station]
```

#### Fluxo de Testes de Hardware
```markdown
## Fluxo de Bancada

```mermaid
flowchart TD
    A[Testes de bancada] --> B[Integracao de sensores]
    B --> C[Simulacao e estudo de asa]
    C --> D[Teste de queda experimental]
    D --> E[Correlacao sim x real]
    E --> F[Integracao de firmware final]
```

## Documentation Review Checklist

### For New Features
- [ ] README.md updated with feature description
- [ ] CHANGELOG.md updated (Unreleased section)
- [ ] API documentation (Doxygen comments)
- [ ] Usage examples provided
- [ ] Hardware requirements documented (if applicable)
- [ ] Configuration options explained

### For Bug Fixes
- [ ] CHANGELOG.md updated (Fixed section)
- [ ] Root cause documented in issue/PR
- [ ] Prevention strategy explained

### For Refactoring
- [ ] Architecture Decision Record created
- [ ] Migration guide provided
- [ ] Breaking changes documented
- [ ] CHANGELOG.md updated (Changed section)

## Tools

### Generate Doxygen Docs
```bash
# Install Doxygen
sudo apt install doxygen graphviz

# Generate documentation
# (se houver Doxyfile no projeto)
```

### Mermaid Live Editor
https://mermaid.live/

### Markdown Linting
```bash
# Install markdownlint
npm install -g markdownlint-cli

# Lint documentation
markdownlint docs/**/*.md
```

## Resources
- Project documentation: `docs/`
- Doxygen manual: https://www.doxygen.nl/
- Mermaid syntax: https://mermaid.js.org/
- Keep a Changelog: https://keepachangelog.com/
- Semantic Versioning: https://semver.org/

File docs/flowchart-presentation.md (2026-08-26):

# Flowchart Simplificado — Helike PocketQube

## Diagrama Unico (Boot + Loop Principal)

```mermaid
flowchart TD
    START[Power On] --> INIT[Init Sensors\nBME280 / ICM-20602 / GPS / LoRa / SD]
    INIT --> MAIN{Main Loop\n200 ms / 5 Hz}
    MAIN -->|sample| READ[Read All Sensors\nBME + ICM + GPS]
    READ --> VALIDATE{Data Valid?\nNaN / Range / Vz ok}
    VALIDATE -->|no| SKIP[Skip Packet]
    VALIDATE -->|yes| VZ[Compute Vz\nEMA alpha=0.4]
    VZ --> FORMAT[Format 18-field CSV]
    FORMAT --> TX[LoRa Transmit\n915 MHz / SF7 / 125 kHz]
    TX --> LOG[Log to Storage\nSD / LittleFS]
    SKIP --> MAIN
    LOG --> MAIN
```

## Pipeline de Validacao

```mermaid
flowchart LR
    RAW[Raw Data] --> NAN{NaN?}
    NAN -->|yes| REJECT[Reject]
    NAN -->|no| ACCEL{Accel\nunder 20 g?}
    ACCEL -->|no| REJECT
    ACCEL -->|yes| PRESS{Pressure\n30-120 kPa?}
    PRESS -->|no| REJECT
    PRESS -->|yes| VZ_RANGE{Vz\nunder 200 m/s?}
    VZ_RANGE -->|no| REJECT
    VZ_RANGE -->|yes| ACCEPT[Valid Data\nTX + Log]
```

## LoRa Packet Flow

```mermaid
sequenceDiagram
    participant S as Satellite
    participant L as LoRa RF
    participant R as Receiver (GS)

    loop Every 200ms
        S->>S: Read + Validate + Compute Vz
        S->>L: Send 18-field CSV
        L-->>R: 915 MHz / SF7
        R->>R: Decode + Add Timestamp + RSSI
        R->>R: Forward 21-field to WebUI
    end
```

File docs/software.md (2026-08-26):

# Software Architecture

## Overview

The satellite firmware runs on an ESP32-C3 Super Mini (single-core RISC-V,
400KB RAM, 4KB default stack). The system uses a continuous loop architecture
with no FSM, no FreeRTOS, and no sleep mode — the satellite powers on already
descending and runs until recovery.

## Architecture Diagram

```mermaid
flowchart LR
    subgraph Sensors
        BME[BME280\nI2C 0x76]
        ICM[ICM-20602\nI2C 0x69]
        GPS[NEO-8M\nUART 9600]
    end

    subgraph Computation
        COLLECT[TelemetryModule\ncollectData]
        VALIDATE[DataValidation\nisValid]
        VZ[VerticalVelocity\nEMA filter]
        FORMAT[TelemetryModule\nformatPacket]
    end

    subgraph Output
        LORA[LoRaModule\nRFM95W 915MHz]
        STORAGE[FilesystemModule\nSD / LittleFS]
        SERIAL[Serial\n115200 baud]
    end

    BME --> COLLECT
    ICM --> COLLECT
    GPS --> COLLECT
    COLLECT --> VALIDATE
    VALIDATE --> VZ
    VZ --> FORMAT
    FORMAT --> LORA
    FORMAT --> SERIAL
    FORMAT --> STORAGE
```

## Module Structure

### `src/main.cpp` — Entry Point

- `setup()`: Initializes Serial, I2C, sensors, then **single SPI bus init
  → LoRa → storage (SD→LittleFS)**, watchdog. Boot order is load-bearing:
  the radio must be configured before any SD mount attempt, and SPI must
  be initialized exactly once (see ADR-005 and hardware.md Known Issues).
- `loop()`: Runs at 5Hz (SAMPLE_INTERVAL_MS = 200ms):
  1. Read GPS (continuous)
  2. Update IMU
  3. Collect sensor data via TelemetryModule
  4. Validate data via DataValidation
  5. Calculate Vz via VerticalVelocity (EMA filter, alpha=0.4)
  6. Build 18-field CSV packet
  7. Transmit via Serial + LoRa
  8. Log to SD/LittleFS
  9. Toggle heartbeat LED
  10. Feed watchdog

### `src/config.h` — Global Configuration

| Section | Key Defines |
|---|---|
| Identification | `TEAM_ID`, `MISSION_NAME` |
| Pinout | `I2C_SDA/SCL`, `LORA_*`, `SD_CS_PIN`, `GPS_*`, `LED/BUZZER_PIN` |
| Timing | `SAMPLE_INTERVAL_MS=200`, `LORA_INTERVAL_MS=200`, `GPS_READ_INTERVAL_MS=1000` |
| LoRa | `LORA_FREQ=915E6`, `SYNC_WORD=0xF3`, `SF=7`, `BW=125E3` |
| Sensors | `BME280_ADDR`, `ICM20602_ADDR`, validation thresholds |
| Watchdog | `WATCHDOG_TIMEOUT_MS=5000` |
| Debug | `DEBUG_ENABLED`, `USE_LITTLEFS` |

### `src/sensors/` — Sensor Drivers

All sensors implement the `ISensor` abstract interface:

- `ISensor.h` — Pure virtual interface (begin, update, isReady, hasNewData, markDataRead)
- `BME280Sensor` — Temperature, pressure, humidity (BME280) or NAN (BMP280 fallback), barometric altitude (I2C)
- `ICM20602Sensor` — 3-axis accelerometer (±16g), 3-axis gyroscope (±2000°/s) via raw I2C
- `GPSSensor` — NEO-8M GPS with TinyGPSPlus parser (UART)

### `src/modules/` — System Modules

| Module | File | Description |
|---|---|---|
| LoRaModule | `LoRaModule.h/.cpp` | RFM95W SPI driver (915MHz, SF7, 125kHz) |
| TelemetryModule | `TelemetryModule.h/.cpp` | Data collection, CSV formatting, transmission |
| FilesystemModule | `FilesystemModule.h/.cpp` | SD primary + LittleFS fallback |
| LEDModule | `LEDModule.h/.cpp` | Heartbeat and status LED (GPIO3) |
| BuzzerModule | `BuzzerModule.h/.cpp` | Startup/error beeps via digitalWrite (GPIO0, active buzzer) |

### `lib/calc/` — Calculation Library (Header-only, No Hardware Deps)

| Module | Description |
|---|---|
| `SensorData.h` | Unified telemetry struct (17 fields) |
| `VerticalVelocity.h` | EMA-filtered Vz from altitude differential |
| `ApogeeDetection.h` | Apogee detection by Vz threshold crossing |
| `DataValidation.h` | NaN and range validation against physical limits |

## Data Flow

### CSV Packet Format (18 fields + end-of-packet marker)

```text
TEAM_ID,millis,count,altp,temp,umi,p,gp,gr,gy,ap,ar,ay,alt,lat,lon,sat,rssi#
```

| Field | Source | Unit | Description |
|---|---|---|---|
| TEAM_ID | config | - | Team identifier (#213) |
| millis | millis() | ms | System timestamp |
| count | TelemetryModule | - | Packet sequence number |
| altp | BME280 | m | Barometric altitude |
| temp | BME280 | °C | Temperature |
| umi | BME280 / BMP280 | % | Humidity (NAN if BMP280 fallback) |
| p | BME280 | hPa | Atmospheric pressure |
| gp | ICM-20602 | rad/s | Gyroscope X |
| gr | ICM-20602 | rad/s | Gyroscope Y |
| gy | ICM-20602 | rad/s | Gyroscope Z |
| ap | ICM-20602 | m/s² | Accelerometer X |
| ar | ICM-20602 | m/s² | Accelerometer Y |
| ay | ICM-20602 | m/s² | Accelerometer Z |
| alt | GPS | m | GPS altitude (MSL) |
| lat | GPS | deg | Latitude |
| lon | GPS | deg | Longitude |
| sat | GPS | - | Satellite count |
| rssi | placeholder | dBm | RSSI (-1, filled by receiver) |
| **#** | **terminator** | - | **End-of-packet marker** |

**`#` end-of-packet marker**: The `#` character terminates every packet. The
ground station receiver uses it to verify integrity: if a line does not end
with `#`, the packet was truncated or corrupted during LoRa transmission and
should be discarded.

Time/date fields are intentionally omitted — they are filled by the ground
station receiver using its local GPS for precise synchronization.

### Validation Pipeline

```mermaid
flowchart LR
    A[Raw Sensor Data] --> B{isNaN?}
    B -->|Yes| C[Reject]
    B -->|No| D{Accel < 20g?}
    D -->|No| C
    D -->|Yes| E{Pressure\n30-120 kPa?}
    E -->|No| C
    E -->|Yes| F{|Vz| < 200 m/s?}
    F -->|No| C
    F -->|Yes| G[Valid Data]
```

### Vertical Velocity (EMA Filter)

Vz is computed using numerical differentiation with an Exponential Moving
Average filter:

```text
vz_raw = (altitude - altitude_prev) / dt
vz_filt = alpha * vz_raw + (1 - alpha) * vz_filt_prev
```

Where `alpha = 0.4` (configured in main.cpp).

### Apogee Detection

Apogee is detected when Vz crosses below a configurable negative threshold
(default: -0.5 m/s). The detector:

- Tracks peak altitude during ascent
- Records the exact timestamp of apogee
- Tracks maximum descent speed after apogee
- Fires only once per flight (single-shot)

## Unit Testing

Three native test suites using the Unity framework:

| Suite | File | Tests | Description |
|---|---|---|---|
| test_vz | `test/test_vz/` | 7 | Vz calculation, EMA, zero dt, reset |
| test_apogee | `test/test_apogee/` | 7 | Detection, tracking, single-shot, reset |
| test_validation | `test/test_validation/` | 11 | NaN, range checks, liberal config |

Run with:

```bash
pio test -e native
```

## Key Design Decisions

1. **No FSM, no sleep** — Satellite powers on already descending
2. **Static global objects** — No heap allocation, deterministic RAM usage
3. **SD primary, LittleFS fallback** — Runtime storage detection
4. **TinyGPSPlus** — Higher-level NMEA parsing vs manual
5. **PlatformIO** — Build + native tests in one toolchain
6. **5Hz sample rate** — 200ms interval, adequate for descent phase

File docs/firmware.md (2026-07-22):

# Firmware Guide

## Build System

The project uses **PlatformIO** with two environments:

| Environment | Target | Purpose |
|---|---|---|
| `helike_esp32c3` | ESP32-C3 | Satellite firmware |
| `native` | PC (x86_64) | Unit tests (Unity) |

### Dependencies

Managed automatically by PlatformIO (`lib_deps` in platformio.ini):

| Library | Version | Used By |
|---|---|---|
| `sandeepmistry/LoRa` | ^0.8.0 | LoRaModule (RFM95W) |
| `adafruit/Adafruit BME280 Library` | ^2.2.4 | BME280Sensor (primary) |
| `adafruit/Adafruit BMP280 Library` | ^2.6.8 | BMP280 fallback |
| `mikalhart/TinyGPSPlus` | ^1.0.3 | GPSSensor |

### Build Configuration

Key settings in `platformio.ini`:

```ini
[env:helike_esp32c3]
board = esp32-c3-devkitm-1
board_build.mcu = esp32c3
board_build.f_cpu = 160000000L
build_src_filter = +<*> -<sensors_disabled/**>
build_flags =
    -D CORE_DEBUG_LEVEL=4
    -D CONFIG_FREERTOS_UNICORE=1
    -D SERIAL_USB_BUFFER_SIZE=64
    -D ARDUINO_USB_MODE=1
    -D ARDUINO_USB_CDC_ON_BOOT=1
    -I lib
```

The `build_src_filter` excludes the `sensors_disabled/` directory (legacy
GPSModule files kept for reference).

## Build and Upload Commands

### Build All

```bash
pio run
```

### Build ESP32-C3 Firmware

```bash
pio run -e helike_esp32c3
```

### Upload to Satellite

```bash
pio run -e helike_esp32c3 -t upload --upload-port /dev/ttyACM0
```

### Serial Monitor

```bash
pio device monitor -b 115200
```

### Run Unit Tests

```bash
pio test -e native            # All tests
pio test -e native -v         # Verbose output
```

## Hardware Test Sketches

Individual `.ino` sketches in `test_hardware/` validate specific hardware
components before integration.

### Sensor tests (`test_hardware/sensor/`)

| Sketch | Tests |
|---|---|
| `bme280/bme280.ino` | BME280 temperature, pressure, humidity, altitude |
| `bmp280/bmp280.ino` | BMP280 temperature, pressure, altitude |
| `gps_neo8m/gps_neo8m.ino` | NEO-8M GPS NMEA parsing |
| `icm20602/icm20602.ino` | ICM-20602 accelerometer, gyroscope |

### Integration tests (`test_hardware/integration/`)

| Sketch | Description |
|---|---|
| `sensor_logging_lfs/` | ICM-20602 + BMP280, LittleFS logging |
| `sensor_logging_lfs_v2/` | v2: +20Hz, Vz, validation, apogee detection |
| `sensor_logging_v3/` | v3: +GPS NEO-8M, 15-column CSV |
| `sensor_logging_fallback/` | SD + LittleFS fallback with persistent file |

### Storage tests (`test_hardware/storage/`)

| Sketch | Description |
|---|---|
| `sd_bare/` | Bare SD card read/write |
| `bmp280_littlefs/` | BMP280 + SPIFFS/LittleFS |
| `sd_littlefs_fallback/` | SD failed -> LittleFS fallback |

### Compile and Upload a Hardware Test

```bash
# Method 1: Using PlatformIO CLI
pio run -e helike_esp32c3 --project-option="src_dir=test_hardware/sensor/bme280"

# Method 2: Open .ino in VS Code with PlatformIO and click Upload
```

## Firmware Boot Sequence

```text
Power On
  │
  ├─ Serial (115200 baud, wait 2s for USB CDC)
  ├─ I2C (400 kHz Fast Mode)
  ├─ Buzzer + LED (indicate startup)
  ├─ BME280/BMP280 (I2C address 0x76, BME280 primary, BMP280 fallback)
  ├─ ICM-20602 (I2C address 0x69, WHO_AM_I = 0x12)
  ├─ GPS (Serial1, 9600 baud)
  ├─ LoRa (RFM95W, 915 MHz)
  ├─ Storage (SD > LittleFS)
  ├─ Watchdog (5s timeout, init before beeps)
  │
  └─ Main Loop (5 Hz)
       ├─ Read GPS
       ├─ Update IMU
       ├─ Collect sensor data
       ├─ Validate (NaN + range checks)
       ├─ Calculate Vz (EMA filter)
       ├─ Format CSV packet
       ├─ Transmit (Serial + LoRa)
       ├─ Log (SD/LittleFS)
       ├─ Toggle LED
       └─ Feed watchdog
```

## Known ESP32-C3 Pitfalls

### 1. USB CDC Serial
`Serial.println()` output is invisible unless compiled with:
```
-D ARDUINO_USB_MODE=1 -DARDUINO_USB_CDC_ON_BOOT=1
```
Without these flags, `Serial` maps to UART0, not the USB CDC port.

### 2. tone() / LEDC
`tone()` crashes with `ledc: ledc_get_duty(): LEDC is not initialized` on ESP32-C3.
**Fix**: Use `ledcSetup()` + `ledcAttachPin()` + `ledcWrite()` instead of `tone()`.
(The BuzzerModule uses `digitalWrite` — active buzzer has built-in oscillator,
so no PWM is needed. The LEDC bug remains relevant for passive buzzers or
PWM-driven peripherals.)

### 3. I2C resetI2C()
Do NOT use GPIO-level I2C bus recovery (`pinMode`/`digitalWrite` on SDA/SCL)
with the ESP32 TwoWire peripheral. It corrupts the I/O MUX configuration.
The `resetI2C()` helper was removed from the firmware for this reason.

The system provides three debug outputs:

1. **Serial console** (115200 baud): All initialization messages and periodic
   debug prints every 2 seconds
2. **LED heartbeat**: Toggles every sample (5 Hz = 10 toggles/sec)
3. **Buzzer tones**: Startup (3 beeps) or error (5 beeps) on init

### Debug Configuration

In `src/config.h`:

```cpp
#define DEBUG_ENABLED      1     // Enable serial debug output
#define LORA_DEBUG_LOGS    0     // Enable LoRa-specific debug
```

### Watchdog

The ESP32-C3 TWDT (Task WatchDog Timer) is configured with a 5-second timeout.
If `esp_task_wdt_reset()` is not called within this window, the system resets.
This prevents lockups from I2C hangs or sensor stalls.

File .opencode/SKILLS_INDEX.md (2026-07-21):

---
title: OpenCode Skills Index
date: 2026-04-06
status: active
---

# OpenCode Skills Index

Este arquivo lista todas as skills disponíveis no projeto Satellite e fornece acesso rápido à documentação.

## Skills Disponíveis

###  Embedded Systems Architect
- **Caminho**: `.opencode/skills/embedded-architect/SKILL.md`
- **Especialidade**: Arquitetura embarcada, organizacao de tasks, otimizacao de performance
- **Use quando**: Planejar arquitetura, validar design, otimizar recursos
- **Responsabilidades**: Design de arquitetura, revisao tecnica, validacao de performance

**Arquivo**: [embedded-architect/SKILL.md](./skills/embedded-architect/SKILL.md)

---

###  Firmware Developer
- **Caminho**: `.opencode/skills/firmware-developer/SKILL.md`
- **Especialidade**: C/C++ embarcado, integração de sensores, protocolos I2C/SPI/UART
- **Use quando**: Implementar drivers, adicionar módulos, corrigir bugs
- **Responsabilidades**: Desenvolvimento de código, integração de sensores, testes unitários

**Arquivo**: [firmware-developer/SKILL.md](./skills/firmware-developer/SKILL.md)

---

###  Code Reviewer (Safety & Quality)
- **Caminho**: `.opencode/skills/code-reviewer/SKILL.md`
- **Especialidade**: Código safety-critical, análise estática, padrões de qualidade
- **Use quando**: Revisar PRs, verificar lógica de segurança, validar padrões
- **Responsabilidades**: Code review, validação de segurança, garantia de qualidade

**Arquivo**: [code-reviewer/SKILL.md](./skills/code-reviewer/SKILL.md)

---

###  Test Engineer
- **Caminho**: `.opencode/skills/test-engineer/SKILL.md`
- **Especialidade**: Unit tests, testes de hardware, simulacao Python, analise de dados
- **Use quando**: Criar testes, validar com simulator, testar hardware
- **Responsabilidades**: Planejamento de testes, validacao, analise de dados

**Arquivo**: [test-engineer/SKILL.md](./skills/test-engineer/SKILL.md)

---

###  Documentation Specialist
- **Caminho**: `.opencode/skills/documentation-specialist/SKILL.md`
- **Especialidade**: Doxygen, ADRs, diagramas, documentação técnica
- **Use quando**: Atualizar docs, criar ADRs, documentar APIs
- **Responsabilidades**: Documentação técnica, ADRs, manutenção de docs

**Arquivo**: [documentation-specialist/SKILL.md](./skills/documentation-specialist/SKILL.md)

---

## Estrutura do Projeto

```
satellite/
├── AGENTS.md                    # Guia para agentes de IA (comandos build, code style)
├── CONTRIBUTING.md              # Padrões de código e processo de PR
├── .opencode/                   # OpenCode configuration
│   ├── README.md               # Visão geral de skills e workflows
│   ├── TEAM.md                 # Estrutura de equipe e matriz RACI
│   ├── opencode.yaml           # Configuração de skills (THIS FILE)
│   ├── SKILLS_INDEX.md         # Índice de skills (YOU ARE HERE)
│   └── skills/                 # Diretórios de skills
│       ├── embedded-architect/
│       │   └── SKILL.md
│       ├── firmware-developer/
│       │   └── SKILL.md
│       ├── code-reviewer/
│       │   └── SKILL.md
│       ├── test-engineer/
│       │   └── SKILL.md
│       └── documentation-specialist/
│           └── SKILL.md
├── firmware/
│   └── ...firmware sources
├── docs/
│   ├── software.md             # Arquitetura de software
│   ├── hardware.md             # Especificações de hardware
│   └── flowchart.md            # Fluxos operacionais
├── extras/
│   ├── wing-analysis/          # Estudos de asa e simulacao
│   └── ...
├── test_hardware/
│   ├── docs/                   # Guias e checklists de bancada
│   ├── sensor/                 # Sketches de sensores
│   └── integration/            # Sketches integrados
└── test/
    └── ...
```

## Workflow Rápido

### Para Implementar uma Nova Feature

1. **Consulte o Architect** (embedded-architect/SKILL.md)
   - Revisar `docs/software.md` para entender a arquitetura
   - Validar design da feature

2. **Implemente com o Developer** (firmware-developer/SKILL.md)
   - Seguir padrões de código em `AGENTS.md`
   - Implementar código seguindo guidelines

3. **Crie Testes com Test Engineer** (test-engineer/SKILL.md)
   - Unit tests com >80% cobertura
   - Validar com simulator Python
   - Testar em hardware

4. **Documente com Doc Specialist** (documentation-specialist/SKILL.md)
   - Adicionar Doxygen comments
   - Atualizar documentação
   - Criar ADR se necessário

5. **Revise com Code Reviewer** (code-reviewer/SKILL.md)
   - Safety-critical code review
   - Validação de padrões
   - Verificação de qualidade

6. **Final Review com Architect**
   - Validação final de arquitetura
   - Aprovação de merge

## Como Acessar uma Skill

### Via OpenCode (Recomendado)
```
"Quero adicionar suporte ao sensor BME280"
→ OpenCode carrega automaticamente as skills relevantes
```

### Manual
```
1. Abra o arquivo `.opencode/skills/[nome-skill]/SKILL.md`
2. Siga as responsabilidades e guidelines
3. Consulte o projeto context específico
```

## Atualizar Informações

Se precisar:
- **Adicionar uma nova skill**: Crie diretório em `.opencode/skills/nova-skill/` com `SKILL.md`
- **Atualizar skill existente**: Edite `.opencode/skills/[skill]/SKILL.md`
- **Atualizar este índice**: Edite este arquivo (`SKILLS_INDEX.md`)
- **Atualizar configuração OpenCode**: Edite `.opencode/opencode.yaml`
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

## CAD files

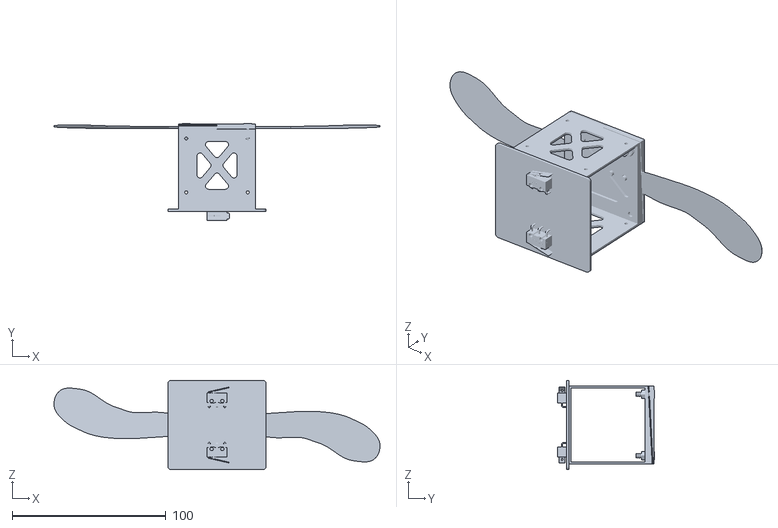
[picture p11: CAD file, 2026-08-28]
docs/landing/data/helike_assy.stl
212.1 x 63.0 x 58.0

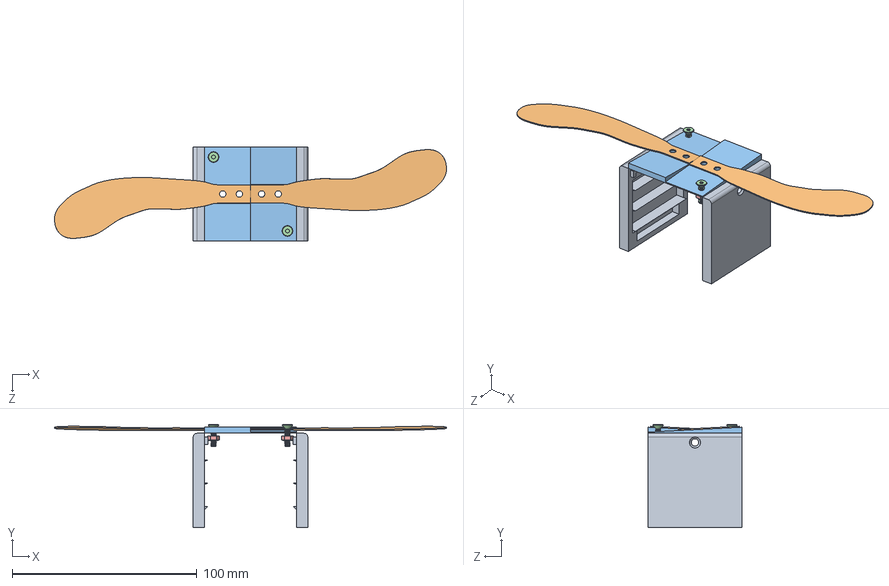
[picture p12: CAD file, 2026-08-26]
hardware/mechanical/assembly/helike_assy.SLDASM
212.1 x 55.7 x 51.0 mm
m3_nut_2_4 x 2
m3_screw_12 x 2
top_support
wing_v3 x 2
side_cover x 2

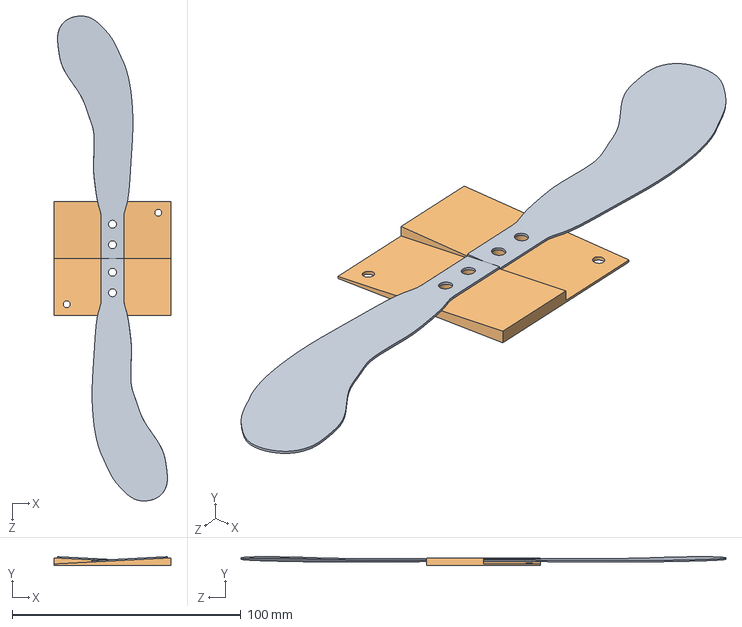
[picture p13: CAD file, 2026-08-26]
hardware/mechanical/srab/assembly/srab_assy.SLDASM
51.0 x 3.80 x 212.1 mm
top_support
wing_v3 x 2

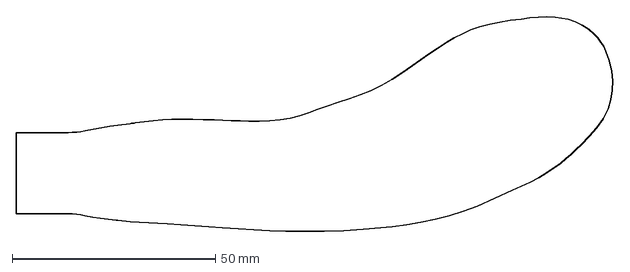
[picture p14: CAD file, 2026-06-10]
extras/wing-analysis/geometry/Asa4.DXF
147.0 x 53.1 mm

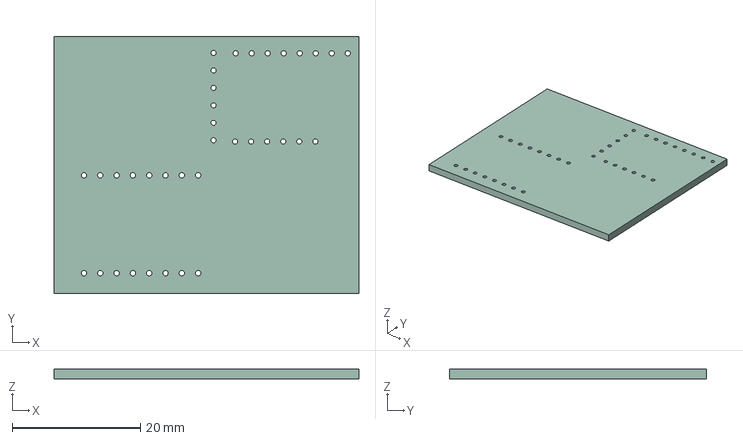
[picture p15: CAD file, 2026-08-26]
hardware/electronics/electronics/PCB.step
47.5 x 40.0 x 1.51 mm

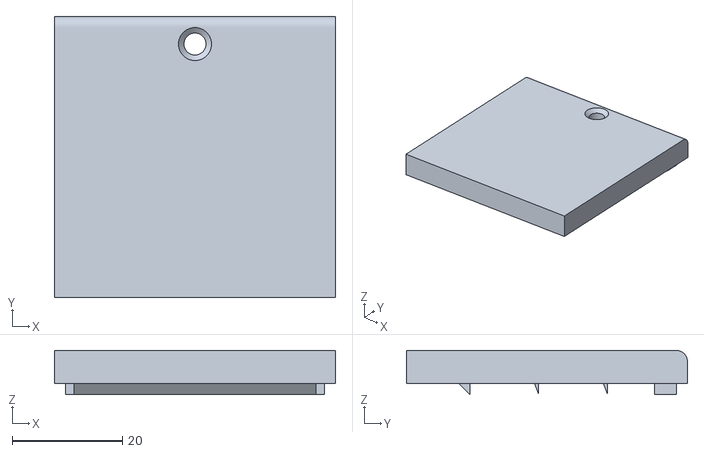
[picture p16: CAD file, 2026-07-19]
hardware/mechanical/chassis/left_cover.STL
51.0 x 51.0 x 8.00

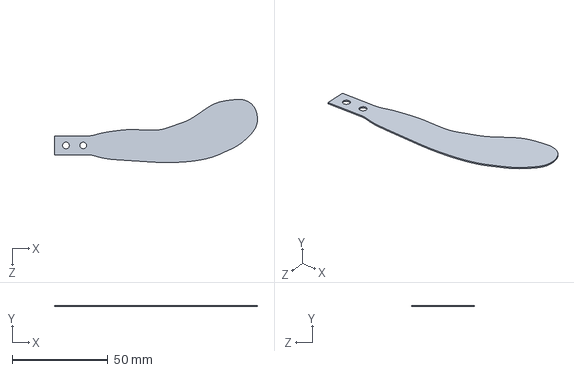
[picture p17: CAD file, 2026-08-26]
hardware/mechanical/srab/parts/wing_v3.SLDPRT
106.0 x 0.6 x 33.0 mm

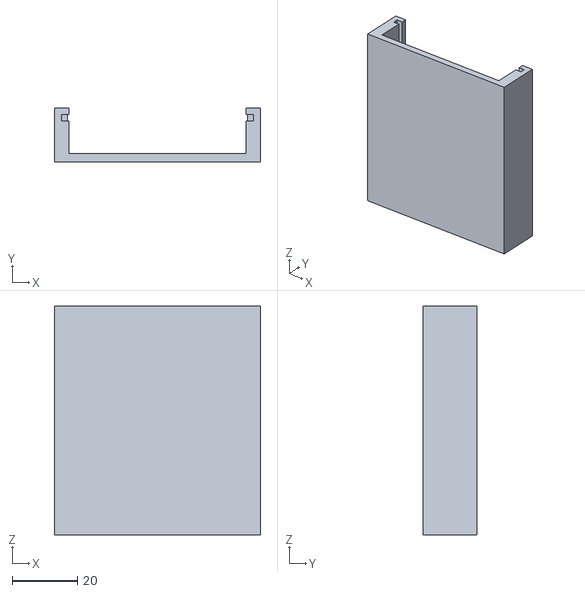
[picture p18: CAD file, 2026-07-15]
hardware/mechanical/standoff/Aerozono-Railtest-v2.stl
63.0 x 16.6 x 70.0

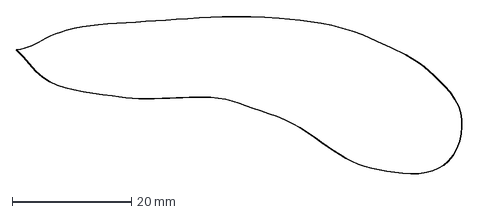
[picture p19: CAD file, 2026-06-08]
extras/wing-analysis/geometry/Asa2-7.5.DXF
75.0 x 26.6 mm

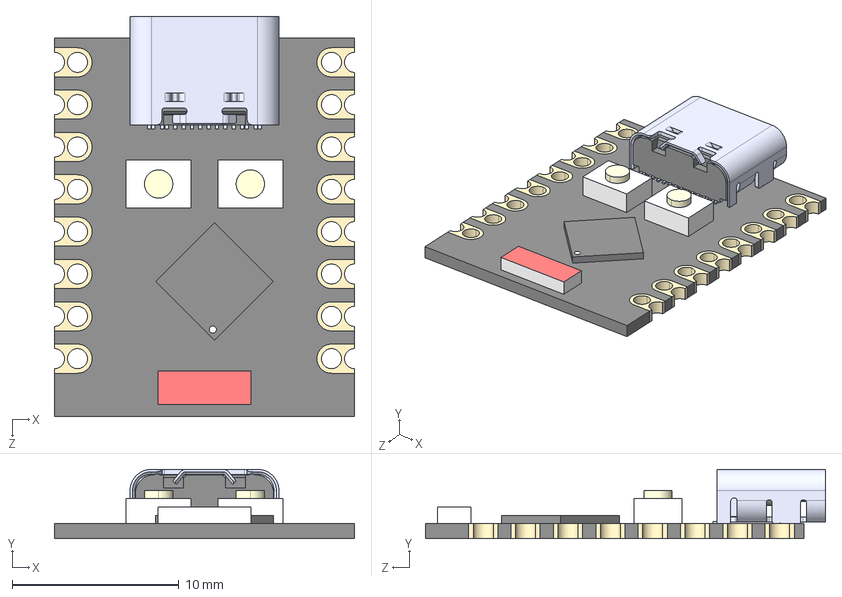
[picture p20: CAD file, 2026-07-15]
hardware/mechanical/electronics/ESP32-C3_SUPERMINI_TH.step
18.0 x 4.16 x 24.0 mm
Board c3mini
USB C
components (other)^ESP32-C3 SuperMini

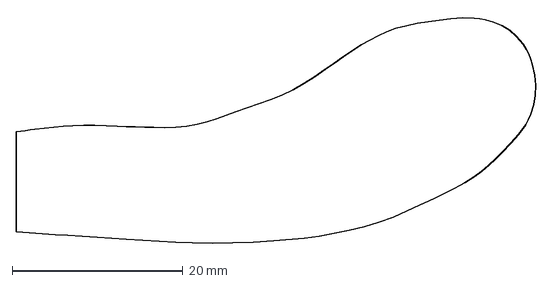
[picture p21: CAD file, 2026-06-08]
extras/wing-analysis/geometry/Asa3.DXF
61.0 x 26.6 mm

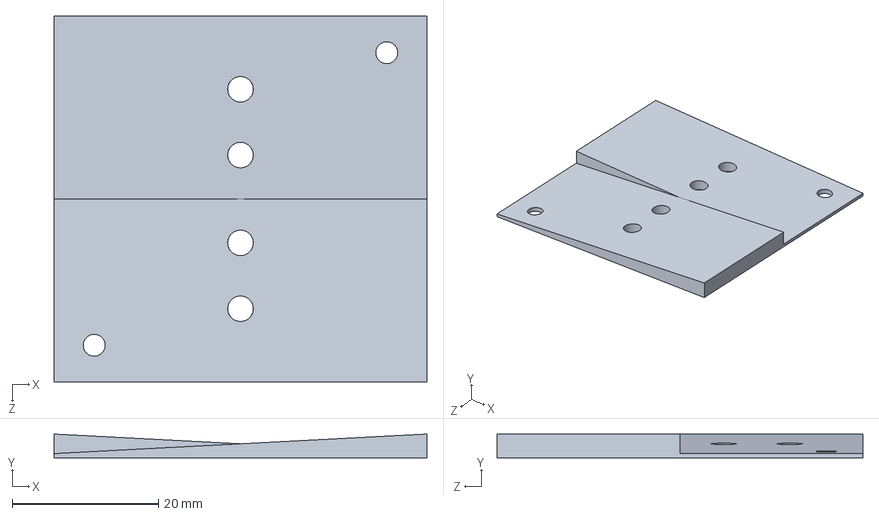
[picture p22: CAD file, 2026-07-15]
hardware/mechanical/srab/parts/top_support.SLDPRT
51.0 x 3.27 x 50.0 mm

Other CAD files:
hardware/electronics/electronics/.step
hardware/mechanical/chassis/side_cover.SLDPRT
hardware/mechanical/srab/parts/wing_v3_sf1.5.STL
hardware/mechanical/chassis/right_cover_temp.SLDPRT
extras/wing-analysis/geometry/Asa2.DXF
extras/wing-analysis/geometry/asa1.dxf
hardware/mechanical/chassis/frame.SLDDRW
hardware/mechanical/chassis/frame.SLDPRT
hardware/mechanical/chassis/right_cover_temp.STL
hardware/mechanical/electronics/PCB.SLDASM
hardware/mechanical/electronics/battery.SLDPRT
hardware/mechanical/electronics/limit_switch.SLDPRT
hardware/mechanical/electronics/limit_switch_2.SLDPRT
hardware/mechanical/srab/assembly/srab_assy.SLDDRW
hardware/mechanical/srab/parts/botton_support.SLDPRT
hardware/mechanical/srab/parts/wing_v2.SLDPRT
hardware/mechanical/standoff/m3_nut.SLDPRT
hardware/mechanical/standoff/m3_nut_2_4.SLDPRT
hardware/mechanical/standoff/m3_screw_12.SLDPRT
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

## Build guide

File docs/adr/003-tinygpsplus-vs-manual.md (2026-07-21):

# ADR-003: TinyGPSPlus vs. Manual NMEA Parsing

## Status

Accepted.

## Context

The test_hardware v3 uses manual NMEA parsing (character-by-character
reading, field extraction, checksum). The TinyGPSPlus library offers
higher-level abstraction with automatic validation.

## Decision

Use TinyGPSPlus as the GPS parser. The manual parsing from v3 is kept as
reference in `test_hardware/integration/sensor_logging_v3/`.

## Rationale

- **Less code, fewer bugs**: TinyGPSPlus implements checksum validation
  and field extraction
- **Testable**: Compiles in native environment for unit tests
- **Stable**: Widely used library in the Arduino/ESP32 community

## Consequences

### Positive

- Cleaner, more maintainable code
- Automatic NMEA checksum validation

### Negative

- TinyGPSPlus adds ~3KB of flash
- Abstraction hides NMEA protocol details

## Alternatives Considered

1. **Manual parsing** (like v3) — more control, but more code and more bugs
2. **TinyGPSPlus** (chosen) — less code, fewer bugs, faster to implement

## Implementation

See `src/sensors/GPSSensor.h` and `src/sensors/GPSSensor.cpp`.

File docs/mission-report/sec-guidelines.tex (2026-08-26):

\begin{enumerate}
\def\labelenumi{\arabic{enumi}.}
\setcounter{enumi}{2}
\item
  \textbf{General Guidelines and Required Elements}
\end{enumerate}

The following section outlines general (non-formatting) guidelines to
follow if desired. Mission Reports will contain all elements identified
in the LASC LCSM, RCSM or SCSM documents, which is available for
download on the LASC website (https://www.lasc.space/documents). Missing
or incomplete elements will result in loss of points. The following
required items are provided for quick reference, and teams should
consult the LCSM, RCSM and SCSM for detailed guidance. Missions are
permitted to add other technical elements to their discretion. No table
of contents is required.

\subsection{Report Body}\label{report-body}

\begin{itemize}
\item
  Abstract
\item
  Introduction
\item
  System Architecture and Concept of Operations
\item
  Weights, Measures, and Performance Data
\item
  Computational Simulation
\item
  Conclusion and Lessons Learned
\end{itemize}

\subsection{Required Report
Appendices}\label{required-report-appendices}

\begin{itemize}
\item
  Hazard Analysis
\item
  Risk Assessment
\item
  Engineering Drawings
\item
  Optional Appendix
\end{itemize}

\subsection{List of References}\label{list-of-references}

\begin{itemize}
\item
  References are required and must follow the format under
  ``References'' at the end of this document.
\end{itemize}

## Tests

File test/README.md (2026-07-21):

# Native Unit Tests

This directory contains the unit tests for the satellite's core logic.

## Framework

We use the **Unity** test framework, running natively on the host machine (PC) instead of the target hardware. This allows for rapid iteration and the use of large datasets for validation.

## Test Suites

- `test_vz/`: Validates the Vertical Velocity calculation and EMA filter accuracy.
- `test_apogee/`: Verifies the apogee detection logic against known flight profiles.
- `test_validation/`: Checks the data validation filters for edge cases and sensor failures.

## How to Run

Use PlatformIO to execute the native tests:

```bash
pio test -e native
```

For more detailed output:
```bash
pio test -e native -v
```

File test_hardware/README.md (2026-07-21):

# Hardware Validation Tests

This directory contains a set of isolated Arduino sketches used to validate individual hardware components and their integration before they are incorporated into the main satellite firmware.

Unlike the main firmware (located in `src/`), these tests are designed to be run as simple Arduino sketches to ensure that the hardware is responding correctly on the bench.

## Structure

```text
test_hardware/
├── docs/               # Bench guides and implementation checklists
├── sensor/             # Isolated sensor tests (BME280, ICM-20602, GPS)
├── storage/            # Filesystem tests (SD Card, LittleFS)
└── integration/        # Multi-sensor logging and fallback tests
```

## How to use

1. Select the appropriate sketch for the component you are testing.
2. Upload the sketch to the ESP32-C3 using the Arduino IDE or PlatformIO.
3. Open the Serial Monitor at 115200 baud to verify the output.
4. Consult the guides in `docs/` for expected behavior and calibration steps.

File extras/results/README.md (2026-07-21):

# Global Simulation Results

This directory contains the final output files from the SRAB aerodynamic simulations.

## Contents

- **Trajectory Maps (`.html`)**: Interactive 3D descent maps.
- **Dashboards (`.png`)**: Performance summaries (LRR - Landing Radius Ratio).
- **Monte Carlo Data (`.csv`)**: Statistical distribution of landing points.
- **Visualization (`.png`)**: 3D trajectory plots and geometry views.

These files are generated by the scripts in `extras/wing-analysis/src/` and represent the final validation for the wing profiles selected for the mission.

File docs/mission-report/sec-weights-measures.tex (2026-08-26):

\begin{enumerate}
\def\labelenumi{\arabic{enumi}.}
\setcounter{enumi}{2}
\item
  \textbf{Weights, Measures, and Performance Data}
\end{enumerate}

\subsection{Physical Characteristics}

\begin{center}
{\small
\setlength{\tabcolsep}{6pt}
\begin{tabular}{>{\raggedright}p{5.2cm}l}
\toprule
\textbf{Parameter} & \textbf{Value} \\
\midrule
Form factor & PocketQube 1P (50$\times$50$\times$50 mm) \\
Mass (estimated) & $\sim$200 g \\
Stowed frontal area & $\sim$25 cm$^2$ \\
Deployed frontal area (SRAB) & $\sim$147 cm$^2$ \\
SRAB wing area & $\sim$122 cm$^2$ (4 wings, Asa2 geometry) \\
\bottomrule
\end{tabular}
}
\end{center}

% TODO: fill measured mass after final integration; the 200 g figure
% is the current estimate used in the SRAB simulation.

\subsection{Recovery Performance}

The SRAB recovery performance was evaluated through two drop-test
campaigns and computational simulation (Section 4):

\begin{center}
{\small
\setlength{\tabcolsep}{6pt}
\begin{tabular}{>{\raggedright}p{5.2cm}l}
\toprule
\textbf{Parameter} & \textbf{Value} \\
\midrule
Terminal velocity (predicted, Test 2) & 10.05 m/s \\
Rotation rate (Test 2) & 439 rpm \\
Cone angle (Test 2) & 11.9$^{\circ}$ \\
SCSM regulatory range & 20--45 m/s \\
Margin vs. lower bound & 50\% below \\
Impact energy dissipated by autorotation & 99.5\% \\
REC 10.2.1 notification (non-parachute) & Sent \\
\bottomrule
\end{tabular}
}
\end{center}

% TODO: update terminal velocity to the final selected configuration
% (Asa3, 2 wings) once the quantitative drop test (Test 4, ~200 m) is
% performed. The computational model currently predicts ~20 m/s for the
% Asa3 2-wing configuration, within the SCSM 20-45 m/s range.

\subsection{Power and Autonomy}

\begin{center}
{\small
\setlength{\tabcolsep}{6pt}
\begin{tabular}{>{\raggedright}p{5.2cm}l}
\toprule
\textbf{Parameter} & \textbf{Value} \\
\midrule
Battery & Li-Ion 6000 mAh \\
Average current draw & $\sim$145 mA \\
Predicted autonomy & $>$40 h \\
SCSM requirement & $\geq$4 h \\
Margin & $>$10$\times$ \\
\bottomrule
\end{tabular}
}
\end{center}

\subsection{Flight Sensors}

\begin{center}
{\small
\setlength{\tabcolsep}{6pt}
\begin{tabular}{>{\raggedright}p{3.2cm}ll}
\toprule
\textbf{Sensor} & \textbf{Type} & \textbf{Measurement} \\
\midrule
ICM-20602 & 6-axis IMU & acceleration + angular rate \\
BME280 & Environmental & pressure, temperature, humidity \\
NEO-8M & GPS & position, velocity, time \\
RFM95W & LoRa radio & 915 MHz telemetry link \\
\bottomrule
\end{tabular}
}
\end{center}

% TODO: add measured mass, measured current draw and final autonomy
% bench test results (with 20% margin evidence) as they become
% available.

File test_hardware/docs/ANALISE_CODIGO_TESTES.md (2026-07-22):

# ANÁLISE TÉCNICA — Código de Testes de Queda (ARQUIVADO)

> **ARQUIVADO**: Esta análise refere-se ao código `sensor_logging_lfs.ino` (v1,
> 500ms, 9 colunas). O firmware atual usa `sensor_logging_v3` (50ms, 15 colunas,
> GPS integrado). Mantido apenas como referência histórica.

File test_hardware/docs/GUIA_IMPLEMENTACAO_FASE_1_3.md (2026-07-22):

# Guia de Implementação - Fase 1.3: Testes Experimentais de Queda
> **NOTA**: BME280 e BMP280 são intercambiáveis. O firmware atual tenta
> BME280 primeiro; se não encontrado, usa BMP280 (umidade = NAN).

## Visao Geral

Este guia detalha como implementar e executar os testes experimentais de queda do freio aerodinâmico usando o código integrado em `sensor_logging_v3.ino`.

**Objetivos**:

1. Validar modelos aerodinâmicos do `extras/wing-analysis/`
2. Medir taxa de descida real vs. simulada
3. Detectar padrão de rotação (estabilidade)
4. Coletar dados para calibração de detecção de apogeu
5. Testar integração de servo motor

---

## Hardware Necessario

### Componentes Eletrônicos

- [ ] **Microcontrolador**: ESP32-C3 Super Mini (ou ESP32)
- [ ] **IMU**: ICM-20602 (acelerômetro + giroscópio)
- [ ] **Sensor Barométrico**: BME280 (pressão/temperatura/umidade)
- [ ] **GPS**: NEO-8M (posição/altitude/velocidade)
- [ ] **Armazenamento**: LittleFS integrado (não precisa SD externo para testes iniciais)
- [ ] **Conectores**: I2C com pull-ups (4.7kΩ normalmente já estão na placa)
- [ ] **Bateria**: USB powerbank 5V para alimentação

### Pinagem (ESP32-C3)

```
I2C Sensors:
  SDA → GPIO 8  (BME280 + ICM-20602)
  SCL → GPIO 9
  GND → GND
  VCC → 3.3V

GPS UART:
  RX → GPIO 20  (recebe dados do GPS NEO-8M)
  TX → GPIO 21  (envia comandos para GPS)
  GND → GND
  VCC → 5V

Serial Debug:
  TX → USB (nativo)
  RX → USB (nativo)
```

### Estrutura Mecânica de Teste

```
┌─────────────────────────────────┐
│  Suporte estrutural (3D print)  │
├─────────────────────────────────┤
│  Asa de Samara (TPU)            │ ← Prototipo a testar
│  - Número: 2/3/4/6 conforme     │
│  - Material: TPU com espessura  │
│  - Raio: conforme simulação     │
├─────────────────────────────────┤
│  Servo Motor (opcional para     │
│  fase 2 - acionamento)          │
├─────────────────────────────────┤
│  Cápsula com sensores:              │
│  - ESP32-C3 + ICM-20602 + BME280 +  │
│  - GPS NEO-8M                       │
│  - Bateria USB powerbank            │
│  - Proteção: foam/cápsula       │
└─────────────────────────────────┘
```

---

## Pre-Requisitos de Software

### 1. Arduino IDE Setup

```bash
# Adicionar board manager URL:
https://raw.githubusercontent.com/espressif/arduino-esp32/gh-pages/package_esp32_index.json

# Em Preferences → Additional Boards Manager URLs
# Instalar: ESP32 boards version 2.0.3+
```

### 2. Bibliotecas Necessárias

```
- Adafruit_BME280 (via Arduino Library Manager)
- Adafruit_Sensor (via Arduino Library Manager)
- Wire (built-in)
- FS (built-in)
- LittleFS (built-in no ESP32)
- HardwareSerial (built-in)
```

### 3. Preparação do Código

```bash
cd test_hardware/integration/sensor_logging_v3/

# Usar versão v3 com todos os componentes
# sensor_logging_v3.ino - integra ICM-20602 + BME280 + GPS NEO-8M

# Ou usar diretamente em Arduino IDE
```

---

## ⚙️ Configuração e Upload

### 1. Conectar Hardware

1. Montagem de protoboard com ICM-20602, BME280 e GPS NEO-8M
2. Conectar GPIO 8 (SDA) e GPIO 9 (SCL) para sensores I2C
3. Conectar GPIO 20 (RX) e GPIO 21 (TX) para GPS UART
4. Alimentar com 3.3V (sensores I2C e ICM), 5V (GPS) e GND
5. Conectar ESP32-C3 via USB-C

### 2. Arduino IDE

```
Tools → Board: ESP32-C3 (ou ESP32 se usar DevKit)
Tools → Upload Speed: 921600
Tools → Port: /dev/ttyACM0 (ESP32-C3) ou /dev/ttyUSB0 (ESP32)
```

### 3. Upload

```
Sketch → Upload (ou Ctrl+U)
```

### 4. Monitorar Serial

```
Tools → Serial Monitor (115200 baud)

Esperado ver:
=== Teste Unificado de Sensores v3 ===
ICM-20602 + BME280 + GPS NEO-8M
✓ ICM20602 encontrado!
✓ BME280 inicializado!
✓ GPS UART inicializado!
✓ LittleFS montado!
=== Taxa de Aquisição: 20 Hz (50 ms) ===
=== Iniciando Leituras ===

[50] A: 0.12 -0.05 9.81 | T:25.34 U:45.23 | Alt: 45.23 Vz: 0.00 | GPS: ...
[100] A: 0.10 -0.03 9.81 | T:25.34 U:45.23 | Alt: 45.23 Vz: 0.00 | GPS: ...
(Aguardando GPS fix...)

[5000] A: 0.12 -0.05 9.81 | T:25.34 U:45.23 | Alt: 45.23 Vz: 0.00 | GPS: OK
```

---

## Checklist de Validação de Hardware (CRÍTICO)

**Executar ANTES de qualquer teste de queda**

### Validação de Níveis Lógicos (GPS TX)

- [ ] **Medir tensão de TX do GPS com multímetro DC**
  - Esperado: 0V ou 3.3V (nunca 5V!)
  - **Risco**: Se GPS transmitir em 5V direto, danificará GPIO 20 (RX) do ESP32-C3
  - **Correção**: Usar level shifter ou resistor voltage divider (10kΩ + 20kΩ)

- [ ] **Verificar fios da antena GPS**
  - A antena deve estar firme e apontando para o céu (teste em local aberto)
  - Verificar se há danos no conector de antena
  - Distância mínima de componentes de alta frequência (LoRa, eletrolíticos)

### Validação de Alimentação

- [ ] **Tensão 3.3V nos sensores I2C (BME280, ICM-20602)**
  - Com multímetro: medir entre VCC e GND dos sensores
  - Esperado: 3.3V ±0.1V
  - Duração: manter por 5 segundos (deve estar estável)

- [ ] **Tensão 5V no GPS NEO-8M**
  - Com multímetro: medir entre VCC e GND do GPS
  - Esperado: 5V ±0.2V
  - Verificar se há condensador de 100µF próximo ao GPS

- [ ] **GND comum entre ESP32, sensores e GPS**
  - Usar multímetro em modo continuidade (deve dar bip)
  - Conectar todas as conexões de GND em um ponto comum

### Validação de Comunicação I2C

- [ ] **Verificar pull-ups nos pinos SDA/SCL**
  - Esperado: resistores de 4.7kΩ entre SDA→3.3V e SCL→3.3V
  - Se não houver, adicionar resistores de pull-up

- [ ] **Teste de scan I2C** (use código de diagnóstico):

  ```cpp
  Wire.begin(8, 9);  // SDA=GPIO8, SCL=GPIO9
  for (byte i = 1; i < 127; i++) {
      Wire.beginTransmission(i);
      if (Wire.endTransmission() == 0) {
          Serial.printf("Encontrado I2C: 0x%02X\n", i);
      }
  }
  ```

  - **BME280**: endereço 0x77 (ou 0x76 se configurado)
  - **ICM-20602**: endereço 0x68

### Validação de UART GPS

- [ ] **Teste de comunicação UART** (use `gps_neo8m.ino`):
  - Serial Monitor deve mostrar strings NMEA: `$GPRMC`, `$GPGGA`
  - Se não receber dados, verificar:
    - Velocidade baud: 9600 (padrão do NEO-8M)
    - Pinos RX/TX invertidos?
    - Fio solto?

- [ ] **Verificar ruído no UART**:
  - Se Serial Monitor mostrar caracteres estranhos ou linhas corrompidas:
    - Aumentar distância entre LoRa e GPS
    - Adicionar ferrite no fio de alimentação do GPS
    - Encurtar cabos (máximo 10 cm)

### Validação de Capacitores e Decoupling

- [ ] **Verificar condensadores próximos aos sensores I2C**
  - Esperado: 100µF eletrônico + 100nF cerâmico perto de VCC
  - Soldagem firme e sem fraturas

### Teste Rápido de Funcionalidade

- [ ] **Executar `sensor_logging_v3.ino` por 2 minutos em repouso**
  - Esperado no Serial Monitor:
    - Aceleração: ~(0, 0, 9.81) m/s² (sem movimento)
    - Temperatura: valor consistente (ex: 25°C)
    - Umidade: valor dentro da faixa (0-100%)
    - Sem "Encontrado I2C: ???" ou erros de paridade

- [ ] **Girar o dispositivo manualmente**
  - Giroscópio deve mostrar valores não-zero enquanto girado
  - Ao parar, deve voltar para ~0

---

## Protocolo de Testes

### Fase 1.3.1: Validação de Bancada (30 min)

**Objetivo**: Confirmar que hardware está funcionando e dados são coletados

**Procedimento**:

1. [ ] Deixar rodando por 2 minutos em repouso
2. [ ] Verificar Serial Monitor: dados consistentes?
3. [ ] Manualmente mover para cima/baixo
   - Esperado: Vz positivo (subindo) → negativo (descendo)
4. [ ] Girar no ar rapidamente
   - Esperado: Mag_giroscopia aumenta

**Sucesso**: CSV sendo preenchido, dados faz sentido

---

### Fase 1.3.2: Teste de Queda Livre (Sem Asa) - 1 hora

**Objetivo**: Estabelecer baseline de queda (referência)

**Setup**:

- Altura: 10 metros (primeiro teste)
- Local: Area aberta, sem obstáculos
- Repetições: 5×

**Procedimento por repetição**:

1. [ ] Resetar ESP32
2. [ ] Deixar gravando (Serial Monitor aberto)
3. [ ] **Iniciar queda de 10m**: largar manualmente
4. [ ] **Recuperar** do chão
5. [ ] Extrair dados via Serial
6. [ ] Salvar como `teste_baseline_rep1.csv`

**Análise esperada**:

```
Tempo de queda: ~1.4 segundos (v = √(2gh) = 14 m/s)
Vz final (fundo): ~-14 m/s
Apogeu: Não (caindo desde início)
Aceleração durante queda: ~9.81 m/s² (gravidade)
```

**CSV típico**:

```
millis,ax,ay,az,gx,gy,gz,pressao_Pa,altura_m,temperatura_C,umidade_pct,vz,mag_giroscopia,lat,lon,alt_gps
0,0.1,-0.05,10.0,0.0,0.0,0.0,101325,50.0,25.3,45.2,0.0,0.0,-23.5521,-46.6333,52.3
50,-0.2,0.15,10.2,-0.001,0.001,0.002,101320,49.96,25.3,45.2,-0.08,0.0024,-23.5521,-46.6333,52.3
100,-0.3,0.10,9.9,0.0,0.001,0.001,101315,49.92,25.3,45.2,-0.16,0.0014,-23.5521,-46.6333,52.3
... (cada 50ms por ~1400ms)
1400,-0.1,0.05,-5.0,0.001,0.0,0.0,100800,35.0,25.2,45.8,-14.3,0.0015,-23.5520,-46.6334,35.2
```

---

### Fase 1.3.3: Teste com Asa Samara (Protótipo 1) - 2 horas

**Objetivo**: Validar freio - compare vs baseline

**Setup**:

- Asa: Config conforme `extras/wing-analysis/` (ex: 2 asas, R=100mm)
- Altura: 10 metros (mesmo que baseline)
- Repetições: 5×

**Procedimento**: Idêntico ao baseline, mas com asa acoplada

**Análise esperada** (se freio funciona):

```
Tempo de queda: ~2.0-3.0 segundos (mais lento!)
Vz final: ~-5 m/s (muito menor que -14 m/s)
Padrão de rotação: Mag_giroscopia alta e constante (autogiro)
Apogeu detector: Pode detectar "flutuação" inicial
```

**Comparação com simulação**:

```
IMPORTANTE: Em quedas de 10m NÃO atingimos regime terminal!
   
Simulação (`extras/wing-analysis/results/test_2_asa2/samara_pq_impact_report.txt`):
   - Config 2×R124mm: v₀ = 27.65 m/s (regime terminal)
   - Config 2×R100mm: v₀ = 27.61 m/s (regime terminal)
   
Esperado no teste (10m, ~2s):
   - Vz_médio = ∫vz(t) dt / tempo
   - Vz_máximo ≈ -8 a -12 m/s (ainda acelerando)
   - Comparar com simulação PARA MESMA ALTURA (usar script Python)
```

---

### Fase 1.3.4: Iteração com Variações (3-4 horas)

**Objetivo**: Otimizar design - testar diferentes configs

**Testes propostos**:

1. **Espessura**: 0.4mm vs 0.6mm vs 0.8mm
2. **Número de asas**: 2 vs 3 vs 4
3. **Raio**: 80mm vs 100mm vs 120mm

**Tabela de Testes** (altura 10m, tempo ~2.0-3.0s):

```
ID  | Config          | Simul v_terminal | Vz_esperado* | Vz_medido | Variação | Status
----|-----------------|------------------|--------------|-----------|----------|--------
T01 | 2 asas,0.6mm    | 27.61 m/s        | -8 a -12 m/s | -9.2 m/s  | ±5%      | ✅
T02 | 2 asas,0.4mm    | 27.61 m/s        | -7 a -11 m/s | -8.8 m/s  | ±4%      | ✅
T03 | 3 asas,0.6mm    | 23.81 m/s        | -9 a -13 m/s | -11.1 m/s | ±3%      | ✅
T04 | 6 asas,0.6mm    | 17.85 m/s        | -11 a -15 m/s| -12.5 m/s | +8%      | (mais lento)

*Vz_esperado = Simulação de altura 10m com mesmo coef. aerodinâmico (não usar v_terminal direto!)
```

**Critério de aceitação**:

- Vz_medido dentro de ±15% da simulação
- Estabilidade em 5 repetições (desvio padrão < 5%)
- Sem danos visíveis à asa

---

## Analise de Dados

### 1. Extrair CSV do LittleFS

**Opção A**: Via Serial Monitor

```
# Após teste, copiar todo output do Serial Monitor
# Salvar como: teste_queda_rep1.csv
```

**Opção B**: Via terminal (direto do Arduino)

```bash
# Em Arduino IDE, Tools > Serial Monitor
# Copiar dados linha por linha
# Ou usar script Python com pyserial
```

### 2. Script Python para Análise

```python
import pandas as pd
import numpy as np
import matplotlib.pyplot as plt

# Carregar dados
df = pd.read_csv('teste_queda_rep1.csv')

# Calcular estatísticas
altitude_max = df['altura_m'].max()
tempo_queda = df['millis'].iloc[-1] / 1000
vz_min = df['vz_ms'].min()
vz_media = df[df['altura_m'] < altitude_max - 1]['vz_ms'].mean()  # Excluir início
aceleracao_max = np.sqrt(df['ax_ms2']**2 + df['ay_ms2']**2 + df['az_ms2']**2).max()
rotacao_media = df['mag_giroscopia_rads'].mean()

print(f"""
=== RESULTADOS DO TESTE ===
Altitude máxima: {altitude_max:.2f} m
Tempo de queda: {tempo_queda:.2f} s
Vz mínimo (máx descida): {vz_min:.2f} m/s
Vz médio (estável): {vz_media:.2f} m/s
Aceleração máxima: {aceleracao_max:.2f} m/s²
Rotação média: {rotacao_media:.6f} rad/s
""")

# Gráficos
fig, ((ax1, ax2), (ax3, ax4)) = plt.subplots(2, 2, figsize=(12, 8))

# Altitude vs Tempo
ax1.plot(df['millis']/1000, df['altura_m'], 'b-', linewidth=2)
ax1.set_xlabel('Tempo (s)')
ax1.set_ylabel('Altitude (m)')
ax1.set_title('Altitude vs Tempo')
ax1.grid()

# Velocidade Vertical
ax2.plot(df['millis']/1000, df['vz_ms'], 'r-', linewidth=2)
ax2.axhline(y=vz_min, color='k', linestyle='--', label=f'Mín: {vz_min:.2f} m/s')
ax2.set_xlabel('Tempo (s)')
ax2.set_ylabel('Vz (m/s)')
ax2.set_title('Velocidade Vertical (negativo = descendo)')
ax2.grid()
ax2.legend()

# Aceleração
acel = np.sqrt(df['ax_ms2']**2 + df['ay_ms2']**2 + df['az_ms2']**2)
ax3.plot(df['millis']/1000, accel, 'g-', linewidth=2)
ax3.axhline(y=9.81, color='k', linestyle='--', label='Gravidade')
ax3.set_xlabel('Tempo (s)')
ax3.set_ylabel('Aceleração (m/s²)')
ax3.set_title('Magnitude de Aceleração')
ax3.grid()
ax3.legend()

# Rotação
ax4.plot(df['millis']/1000, df['mag_giroscopia_rads'], 'm-', linewidth=2)
ax4.set_xlabel('Tempo (s)')
ax4.set_ylabel('Rotação (rad/s)')
ax4.set_title('Magnitude do Giroscópio')
ax4.grid()

plt.tight_layout()
plt.show()

# Exportar summary
with open('teste_queda_rep1_analise.txt', 'w') as f:
    f.write(f"""
TESTE DE QUEDA - ANÁLISE
=======================
Data: {pd.Timestamp.now()}

Estatísticas:
- Altitude máxima: {altitude_max:.2f} m
- Tempo de queda: {tempo_queda:.2f} s
- Vz mínimo: {vz_min:.2f} m/s
- Vz médio: {vz_media:.2f} m/s
- Aceleração máxima: {aceleracao_max:.2f} m/s²
- Rotação média: {rotacao_media:.6f} rad/s

Validações:
- Apogeu detectado: {df['altura_m'].diff().min() < 0}
- Impacto detectado: {aceleracao_max > 15}
""")
```

### 3. Comparar com Simulação

```python
# Dados da simulação (extras/wing-analysis/results/test_2_asa2/samara_pq_impact_report.txt)
# Terminal velocities por configuração:
# - 2×R124mm: v₀ = 27.65 m/s
# - 2×R100mm: v₀ = 27.61 m/s
# - 3×R124mm: v₀ = 23.81 m/s
# - 6×R100mm: v₀ = 17.85 m/s (recomendado)

import pandas as pd
import numpy as np

df_teste = pd.read_csv('teste_queda_rep1.csv')

# Extrair dados estáveis (excluir primeiros/últimos 500ms)
tempo_estavel = df_teste[(df_teste['millis'] > 500) & (df_teste['millis'] < (df_teste['millis'].max() - 500))]
vz_estavel_medio = tempo_estavel['vz'].mean()
vz_estavel_std = tempo_estavel['vz'].std()

simul_config = "2 asas, R=100mm"
simul_vz_terminal = 27.61  # m/s (absoluto, descendo)

print(f"""
COMPARAÇÃO SIMULAÇÃO vs TESTE
============================
Config: {simul_config}
Simulação (regime terminal): {simul_vz_terminal:.2f} m/s
Teste real (Vz médio estável): {abs(vz_estavel_medio):.2f} ± {vz_estavel_std:.2f} m/s

 NOTA: Teste em 10m NÃO atinge regime terminal
   Compare com simulação para MESMA ALTURA usando script de física
   (calcular posição teórica em t=tempo_queda_real)

Critério: Desvio padrão (5 reps) < 5% da média
Status: {"VALIDADO" if vz_estavel_std < (abs(vz_estavel_medio) * 0.05) else "REJEITAR - Instabilidade"}
""")
```

---

## Iteracao e Ajustes

### Se Vz for TOO FAST (>-8 m/s)

→ Aumentar área das asas

- Aumentar raio: 100mm → 120mm
- Aumentar espessura: 0.6mm → 0.8mm
- Adicionar mais asas: 2 → 3 ou 4

### Se Vz for TOO SLOW (<-2 m/s)

→ Diminuir área das asas

- Diminuir raio: 100mm → 80mm
- Diminuir espessura: 0.6mm → 0.4mm
- Menos asas: 4 → 3 ou 2

### Se Padrão for INSTÁVEL (Rotação inconsistente)

→ Revisar design mecânico

- Verificar simetria das asas
- Aumentar raio para estabilizar (momento angular maior)
- Testar em altura maior (mais tempo para estabilizar)

---

## Cronograma Sugerido

```
Semana 1:
  Seg-Ter: Setup hardware, validação de bancada (Fase 1.3.1)
  Qua-Qui: Testes de baseline (Fase 1.3.2) - 5 quedas
  Sex: Análise e preparação de asas

Semana 2:
  Seg-Ter: Testes com asa protótipo 1 (Fase 1.3.3) - 5 quedas
  Qua: Análise comparativa vs simulação
  Qui-Sex: Iteração com variações (Fase 1.3.4) - 3 configs

Semana 3:
  Seg-Ter: Testes finais, validação
  Qua: Documentação de resultados
  Qui-Sex: Ajustes finais para integração com servo
```

---

## Checklist de Execucao

### Pré-Teste

- [ ] Hardware montado e testado
- [ ] Código v2 melhorado carregado
- [ ] Serial Monitor funcionando
- [ ] Bateria carregada
- [ ] Area de queda segura (sem pessoas)
- [ ] Câmera de vídeo preparada (opcional - para análise visual)

### Durante Teste

- [ ] Anotar: configuração, altura, peso, clima
- [ ] Realizar 5 repetições idênticas
- [ ] Monitorar Serial para eventos (Apogeu?)
- [ ] Registrar duração de queda manualmente (cronômetro)
- [ ] Fotografar/Filmar cada queda

### Pós-Teste

- [ ] Extrair CSV do ESP32
- [ ] Executar script de análise Python
- [ ] Comparar com simulação
- [ ] Documentar resultados
- [ ] Decidir próximos ajustes

---

## Troubleshooting

### "GPS mostra apenas pontos (... em vez de OK)"

- [ ] GPS precisa de 30-60 segundos para primeiro fix
- [ ] Ficar em local aberto (mais de 45° de céu visível)
- [ ] Verificar antena GPS - deve estar apontando para cima
- [ ] Problema: GPS perto de grandes estruturas metálicas → afastar 10m
- [ ] Se permanecer como "..." por > 2 min: verificar UART RX/TX nos pinos 20/21

### "Apogeu não é detectado"

- [ ] Verificar se `altura` está aumentando no início
- [ ] Aumentar altura de queda (maior Vz para detectar)
- [ ] Verificar threshold: `if (vz < -0.5)` - ajustar se necessário

### "Dados erráticos ou NaN"

- [ ] Verificar conexão I2C (pull-ups OK?)
- [ ] Reset barramento: ligar/desligar power
- [ ] Verificar solda nos pinos
- [ ] Para GPS: verificar se está recebendo serial (coloque breakpoint na UART)

### "Velocidade vertical não muda"

- [ ] Verificar se `millis_anterior` está sendo atualizado
- [ ] Aumentar altura de queda
- [ ] Verificar se BME280 está calibrado (1013.25 hPa correto?)

### "ESP32 não grava dados"

- [ ] Verificar if LittleFS está montado (Serial output)
- [ ] Tentar formatar LittleFS: Menu → Tools → Erase All Flash Contents
- [ ] Testar com Serial Monitor (não via CSV)

### "BME280 mostra pressão constantemente igual"

- [ ] Verificar endereço I2C: é 0x76 ou 0x77? (SDO=GND vs VCC)
- [ ] Se o jumper SDO não está conectado, tente 0x77
- [ ] Validar com teste isolado: `test_hardware/sensor/bme280/bme280.ino`

---

## Proximos Passos Apos Validacao

1. **Integração de Servo Motor**
   - Disparar em apogeu automático
   - Testar confiabilidade

2. **Integração de GPS**
    - Validação cruzada de altitude GPS vs BME280
    - Registrar posição de pouso
    - Testar confiabilidade em ambiente aberto

3. **Refinamento de Detecção de Apogeu**
   - Usar dados reais dos testes para calibração
   - Validar estado de máquina

4. **Firmware Final do Satélite**
   - Integrar todo código em firmware.ino
   - Adicionar lógica de acionamento de servo
   - Preparar para lançamento real

---

**Status**: Pronto para testes
**Última atualização**: 09/04/2026  
**Responsável**: Time de Desenvolvimento

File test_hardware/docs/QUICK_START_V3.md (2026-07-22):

# Quick Start - Novos Testes (GPS + BME280)

## Instalação Rápida de Bibliotecas

```bash
# Arduino IDE → Tools → Manage Libraries

Procurar e instalar:
Adafruit_BME280 (or BMP280)
Adafruit_Sensor
```

Já estão built-in:

- `Wire` (I2C)
- `HardwareSerial` (UART)
- `LittleFS` (Storage)

---

## Teste GPS Isolado

**Arquivo**: `test_hardware/sensor/gps_neo8m/gps_neo8m.ino`

**Hardware**:

```
GPS NEO-8M          ESP32-C3
VCC (5V)     ──────► 5V
GND          ──────► GND
RX (dados)   ──────► GPIO 20 (RX)
TX (comando) ──────► GPIO 21 (TX)
```

**Setup Arduino IDE**:

- Board: ESP32-C3
- Upload Speed: 921600
- Port: /dev/ttyACM0

**Serial Output Esperado**:

```
=== Teste GPS NEO-8M ===
GPS UART inicializado
Aguardando dados NMEA...

--- Status GPS ---
Satélites vistos: 0
Fix quality: Sem fix
Fix type: Sem fix
Aguardando fix GPS...

(após 30-60 segundos em local aberto)

Satélites vistos: 8
Fix quality: GPS fix
Fix type: 3D
Latitude: -23.552140
Longitude: -46.633400
Altitude: 750.23 m
Velocidade: 0.00 km/h
HDOP: 1.2 | VDOP: 1.5
```

**Troubleshooting**:

- Sem dados: Verificar UART RX/TX (pinos 20/21)
- Sem fix por > 2 min: Ficar em local aberto (céu > 45°)
- Dados erráticos: Verificar alimentação 5V do GPS

---

## Teste BME280 Completo

**Arquivo**: `test_hardware/sensor/bme280/bme280.ino`

**Hardware**:

```
BME280           ESP32-C3
VCC (3.3V) ─────► 3.3V
GND        ─────► GND
SDA        ─────► GPIO 8
SCL        ─────► GPIO 9
(SDO=GND para endereço 0x76)
```

**Serial Output Esperado**:

```
=== Teste BME280 ===
Procurando BME280 no endereço 0x76
BME280 encontrado!
Sensor configurado
  - Modo: Normal
  - Amostragem: 2x (todos)
  - Tempo espera: 1000ms

--- Dados BME280 ---
Leituras: 1 | Erros: 0
Temperatura: 25.34 °C
Pressão: 1013.25 hPa (101325 Pa)
Umidade: 45.23 % RH
Altitude: 45.23 m (ISA, P0=101325 Pa)
Ponto orvalho: 14.56 °C
Índice calor: 26.78 °C
```

**Troubleshooting**:

- Sensor não encontrado: Verificar I2C (pinos 8/9), tentar endereço 0x77
- Valores constantes: Reset I2C (desligar/ligar power)
- Dados NaN: Verificar solda/conexão

---

## ⭐ Teste Integrado v3 (RECOMENDADO)

**Arquivo**: `test_hardware/integration/sensor_logging_v3/sensor_logging_v3.ino`

**Hardware Completo**:

```
I2C Sensors (SDA=GPIO8, SCL=GPIO9):
├─ ICM-20602 (0x69)
│  VCC (3.3V)
│  GND
│  SDA → GPIO 8
│  SCL → GPIO 9
│
└─ BME280 (0x76)
   VCC (3.3V)
   GND
   SDA → GPIO 8
   SCL → GPIO 9

UART GPS (RX=GPIO20, TX=GPIO21):
├─ VCC (5V)
├─ GND
├─ RX → GPIO 20
└─ TX → GPIO 21
```

**Serial Output Esperado**:

```
=== Teste Unificado de Sensores v3 ===
ICM-20602 + BME280 + GPS NEO-8M

=== Inicializando Sensores ===
ICM20602 encontrado!
BME280 inicializado!
GPS UART inicializado!
LittleFS montado!

=== Status dos Sensores ===
ICM20602: OK
BME280:   OK
GPS:      OK
Storage:  OK

=== Taxa de Aquisição: 20 Hz (50 ms) ===
=== Iniciando Leituras ===

[50] A: 0.12 -0.05 9.81 | T:25.34 U:45.23 | Alt: 45.23 Vz: 0.00 | GPS: ...
[100] A: 0.10 -0.03 9.81 | T:25.34 U:45.23 | Alt: 45.23 Vz: 0.00 | GPS: ...

(após 30-60s com GPS fix)

[5000] A: 0.12 -0.05 9.81 | T:25.34 U:45.23 | Alt: 45.23 Vz: 0.00 | GPS: OK
```

**CSV Gerado** (LittleFS):

```
arquivo: /sensores_v3.csv

Colunas (15):
millis, ax, ay, az, gx, gy, gz, pressao_Pa, altura_m, 
temperatura_C, umidade_pct, vz, mag_giroscopia, lat, lon, alt_gps

Exemplo:
0,0.1,-0.05,10.0,0.0,0.0,0.0,101325,50.0,25.3,45.2,0.0,0.0,-23.5521,-46.6333,52.3
```

**Como Acessar Dados**:

1. Arduino IDE → Tools → LittleFS → Upload Data
2. Aguardar testes
3. Arduino IDE → Tools → Serial Monitor
4. Dados já visíveis no monitor + salvos no CSV

---

## Fluxo de Testes Recomendado

1. **Validação Individual** (se houver problemas):
   - `gps_neo8m.ino` → valida GPS UART
- `bme280.ino` → valida sensor barométrico

2. **Teste Integrado** (para Fase 1.3):
- `sensor_logging_v3.ino` → coleta tudo junto
   - Deixar rodando enquanto executa queda
   - Extrair CSV do LittleFS

3. **Análise de Dados**:

   ```bash
   # Pós-processamento (Python)
   python extras/wing-analysis/src/samara_pq_simulation.py
   
   # Gera:
   - Gráfico Vz vs tempo
   - Detecção de apogeu
   - Validação altitude GPS vs BME280
   - Estatísticas de rotação (giroscópio)
   ```

---

## ⚙️ Configurações Importantes

**v3.ino - Principais #defines**:

```cpp
#define INTERVAL_MS 50              // Taxa: 20 Hz
#define MAX_ACCEL_G 50.0            // Validação: aceleração suspeita > 5g
#define MIN_PRESSURE_PA 300         // Validação: pressão mínima
#define MAX_PRESSURE_PA 120000      // Validação: pressão máxima
#define APOGEE_THRESHOLD_MS 100     // Tempo mínimo em descida p/ apogeu
```

**Calibração de Altitude**:

```cpp
#define PRESSAO_MAR_PA 101325.0     // Ajustar se necessário
// Usar valor local de P0 para maior precisão
```

---

## Troubleshooting Rapido

| Problema | Solução |
|---|---|
| **GPS: ...** por > 2 min | Ficar em local aberto, 45° de céu mínimo |
| **GPS: Sem dados** | Verificar pinos 20/21, alimentação 5V |
| **BME280 não encontrado** | I2C pull-ups OK? Endereço 0x76 ou 0x77? |
| **I2C erros** | Reset: ligar/desligar power, não soldar pinos |
| **CSV vazio** | Verificar LittleFS mounted, usar `Erase Flash` |
| **Apogeu não detecta** | Aumentar altura de queda, verificar Vz |
| **Dados NaN** | Validação falhou, revisar ranges #defines |

---

**Última atualização**: 09/04/2026  
**Status**: ✅ Pronto para Fase 1.3

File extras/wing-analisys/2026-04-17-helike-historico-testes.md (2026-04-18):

---
title: Histórico de Testes Helike (Campo + Simulação)
date: 2026-04-17
captured: 2026-04-17 14:30
type: reference
status: active
project: helike
tags: [helike, testes, simulação, aerodinâmica]
related: []
---

# Histórico de Testes - Projeto Helike (com Simulação Computacional)

## Visão Geral

Registro completo do histórico de testes de protótipos do projeto Helike utilizando estrutura básica 1P da Alba Orbital, com validação via simulação aeronáutica (Samara PQ).

---

## Teste #1 - 01/04/2026 (asa1.dxf)

**Data**: 01 de abril de 2026  
**Estrutura**: Alba Orbital 1P básica  
**Asas utilizadas**: 4 asas (asa1.dxf)
**Modelo DXF processado**: `asa1.dxf`

### Observações de Campo

- Modelo apresenta sustentação detectável
- Estrutura com limitações aerodinâmicas
- Asa não está paralela ao backplate (desalinhamento)
- Status: Sem eletrônica embarcada

### Dados de Simulação (Samara PQ)

| Métrica | Valor |
|---|---|
| **Tempo de voo** | 97.33 s |
| **Velocidade de impacto** | 10.33 m/s |
| **Energia cinética de impacto** | 13.33 J |
| **Taxa de rotação** | 444.86 rpm |
| **Ângulo de pitch (impacto)** | 6.14° |
| **Área total de asas** | 109.22 cm² |
| **Área frontal total** | 134.22 cm² |
| **Número de Reynolds médio** | 13,246 |
| **Energia dissipada** | 2,439.17 J (99.5%) |

### Conclusões

Protótipo viável em termos aerodinâmicos, mas com limitações estruturais. Dissipação de energia confirmada. Design com potencial para otimização.

---

## Teste #2 - 08/04/2026 (Asa2.DXF)

**Data**: 08 de abril de 2026  
**Estrutura**: Alba Orbital 1P (reposicionada)  
**Asas utilizadas**: 4 asas (Asa2.DXF - novo modelo)
**Modelo DXF processado**: `Asa2.DXF`

### Observações de Campo

- Melhoria significativa em relação ao Teste #1 ✓
- Reposicionamento das asas bem-sucedido ✓
- Novo modelo de asa com melhor desempenho ✓
- Bom comportamento rotacional durante queda ✓
- Afetado por carregamento de vento (esperado)
- Status: Sem eletrônica embarcada

### Dados de Simulação (Samara PQ)

| Métrica | Valor |
|---|---|
| **Tempo de voo** | 100.02 s |
| **Velocidade de impacto** | 10.05 m/s |
| **Energia cinética de impacto** | 12.62 J |
| **Taxa de rotação** | 439.08 rpm |
| **Ângulo de pitch (impacto)** | 11.89° |
| **Área total de asas** | 122.28 cm² |
| **Área frontal total** | 147.28 cm² |
| **Número de Reynolds médio** | 18,270 |
| **Energia dissipada** | 2,439.88 J (99.5%) |

---

## Análise Comparativa: Test 1 vs Test 2

### Melhorias Confirmadas em Asa2.DXF

| Parâmetro | Test 1 | Test 2 | Melhoria |
|---|---|---|---|
| Velocidade de impacto | 10.33 m/s | 10.05 m/s | **-2.7%** ✓ |
| Energia de impacto | 13.33 J | 12.62 J | **-5.4%** ✓ |
| Tempo de voo | 97.33 s | 100.02 s | **+2.8%** ✓ |
| Área de asa | 109.22 cm² | 122.28 cm² | **+12.0%** ✓ |
| Área frontal | 134.22 cm² | 147.28 cm² | **+9.7%** ✓ |
| Taxa de rotação | 444.86 rpm | 439.08 rpm | -1.3% (estável) |
| Reynolds médio | 13,246 | 18,270 | +37.9% (fluxo melhor) |

### Conclusão da Análise

✓ **Asa2.DXF apresenta melhoria mensurável:**

- **Pouso mais suave**: velocidade de impacto reduzida em 2.7%
- **Menor energia de choque**: 5.4% de redução em impacto
- **Voo mais longo**: 2.8% de aumento no tempo de descida
- **Aerodinâmica superior**: +12% em área de asa, +9.7% em área frontal
- **Equilíbrio giroscópico mantido**: taxa de rotação estável
- **Número de Reynolds aumentado**: indicação de regime de escoamento mais favorável

**Os dados simulados corroboram as observações de campo do teste de 08/04.**

---

## Próximos Passos

### Críticos (para Teste #3)

- [x] Analisar dados simulados dos dois testes comparativamente ✓
- [ ] **Integração de Eletrônica Embarcada (MANDATÓRIO para Test #3)**
  - GPS para validação de altitude/trajetória
  - Acelerômetro IMU para validação de g-force de impacto
  - Dados LoRa para telemetria em tempo real
  - Justificativa: **Necessário validar predições de simulação com dados reais**
  - Margem de massa disponível: ~15g (250g regulatório - 235g estrutura)
  - Candidato: Asa2.DXF (aerodinâmica validada, área suficiente)

### Secundários

- [ ] Executar Teste #3 com Asa3.dxf (otimizada) + eletrônica
- [ ] Comparar dados simulados vs reais (aceleração, velocidade, trajetória)
- [ ] Documentar lições aprendidas em [[design-otimizacao-samara]]
- [ ] Considerar escalonamento para protótipo com 2 asas vs 6 asas
- [ ] Publicar resultados comparativos (sim vs real) em relatório LASC

---

## Artefatos Técnicos

### Scripts de Simulação

- **Localização**: `/satellite/extras/wing-analisys/`
- **Script principal**: `samara_pq_simulation.py`
- **Manual de uso**: `samara_pq_usage_manual.md`
- **Quickstart**: `samara_pq_quickstart.md`

### Modelos DXF Utilizados

- `asa1.dxf` - Primeiro design (Test #1)
- `Asa2.DXF` - Design otimizado (Test #2)
- `Asa3.dxf` - Próximo candidato para Test #3

### Relatórios Salvos

- `test_1_asa1/samara_pq_impact_report.json`
- `test_2_asa2/samara_pq_impact_report.json`
- Visualizações PNG (LRR reports, frontal area)

---

## Referências e Links

- [[satellite]] - Projeto satélite principal
- [[Alba-Orbital-1P]] - Padrão estrutural Alba Orbital
- `samara_pq_simulation.py` - Pipeline de simulação
- `/satellite/extras/wing-analisys/` - Diretório de análise

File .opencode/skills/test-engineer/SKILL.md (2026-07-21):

---
name: test-engineer
description: Test engineer specializing in embedded systems validation, hardware-in-the-loop testing, and simulation-based verification.
license: MIT
compatibility: opencode
---

## Expertise
- Unit testing for embedded systems
- Hardware-in-the-loop (HIL) testing
- Python-based simulation and data analysis
- Test automation and CI/CD
- Data analysis and validation

## Responsibilities
1. **Create Test Plans**
   - Define test cases for each module
   - Specify acceptance criteria
   - Document test procedures
   
2. **Implement Tests**
   - Write unit tests (Unity framework)
   - Create hardware test firmware
   - Develop Python simulators
   
3. **Validate System**
   - Run validation with real data
   - Perform bench tests
   - Analyze telemetry logs

## Testing Pyramid

```
         /\
        /  \  Manual Hardware Tests
       /____\
      /      \ Hardware-in-Loop (Arduino)
     /________\
    /          \ Unit Tests (Native)
   /____________\
  /              \ Simulation (Python)
 /________________\
```

## Test Types

### 1. Simulation Tests (Python)

**Purpose**: Validate algorithms with real data before hardware testing

**Location**: `extras/wing-analysis/`

#### Wing Analysis Validation
**File**: `src/samara_pq_simulation.py`

**Usage**:
```bash
python extras/wing-analysis/src/samara_pq_simulation.py
```

**What it Tests**:
- Parametric impact on descent metrics
- Sensitivity to geometry changes
- Consistency of simulation outputs

**Expected Output**:
```
Simulation completed
Outputs generated in extras/wing-analysis/results/
```

**Creating New Simulation Tests**:
```python
import numpy as np
import pandas as pd
import matplotlib.pyplot as plt

# Load simulation outputs
df = pd.read_csv('extras/wing-analysis/results/test_1_asa1/samara_pq_impact_report.csv')

# Extract metrics
velocity = df['velocity'].values

# Calculate derived values
v_mean = np.mean(velocity)

# Simple sanity check
assert v_mean > 0, "Invalid mean velocity"
print("Simulation metrics validated")
```

---

### 2. Unit Tests (Native C++)
**Framework**: Unity Test Framework (PlatformIO)

**Location**: `test/`

**Setup**:
```ini
; platformio.ini
[env:native]
platform = native
test_framework = unity
build_flags = -std=c++11
```

#### Example: Sensor Unit Test
**File**: `test/test_native/test_calc_validation.cpp`

```cpp
#include <unity.h>
#include "lib/calc/DataValidation.h"

static float mock_pressure_pa = 101325.0f;

void setUp(void) {
  // Setup before each test
}

void tearDown(void) {
  // Cleanup after each test
}

// Test: Pressure validation
void test_pressure_validation(void) {
  SensorData data = {};
  data.pressao = mock_pressure_pa;
  data.ax = data.ay = data.az = 0.0f;
  data.altura = 0.0f;
  data.vz = 0.0f;
  DataValidation dv;
  TEST_ASSERT_TRUE(dv.isValid(data));
}

// Test: NaN handling
void test_nan_handling(void) {
  SensorData data = {};
  data.pressao = NAN;
  DataValidation dv;
  TEST_ASSERT_FALSE(dv.isValid(data));
}

// Test: Range guard
void test_range_guard(void) {
  SensorData data = {};
  data.pressao = 10.0f;
  DataValidation dv;
  TEST_ASSERT_FALSE(dv.isValid(data));
}

int main(int argc, char **argv) {
  UNITY_BEGIN();
  
RUN_TEST(test_pressure_validation);
RUN_TEST(test_nan_handling);
RUN_TEST(test_range_guard);
  
  return UNITY_END();
}
```

**Run Tests**:
```bash
pio test -e native
```

**Expected Output**:
```
test/test_native/test_bmp585.cpp:45: test_altitude_calculation [PASSED]
test/test_native/test_bmp585.cpp:56: test_nan_handling [PASSED]
test/test_native/test_bmp585.cpp:67: test_vertical_velocity [PASSED]

------------------
3 Tests 0 Failures 0 Ignored
OK
```

---

### 3. Hardware Tests (Arduino)

**Purpose**: Validate modules with real hardware

**Location**: `test_hardware/`

#### Sensor Integration Test
**File**: `test_hardware/integration/sensor_logging_v3/sensor_logging_v3.ino`

```cpp
// Veja o sketch de integracao em test_hardware/integration/sensor_logging_v3/
// Ele cobre ICM-20602, BME280 e GPS NEO-8M com logging em LittleFS.
```

**Test Procedure**:
1. Upload firmware to ESP32-C3
2. Open Serial Monitor (115200 baud)
3. Observe initialization logs
4. Move board up/down and observe altitude/vz
5. Confirm CSV is written in LittleFS

**Expected Output**:
```
=== Teste Unificado de Sensores v3 ===
 ICM20602 encontrado!
 BME280 initialized!
 GPS UART initialized!
 LittleFS montado!
```

---

## Test Data Management

### Bench Data
**Location**: `test_hardware/integration/`

**Format**:
```csv
millis,ax,ay,az,gx,gy,gz,pressao_Pa,altura_m,temperatura_C,umidade_pct,vz,mag_giroscopia,lat,lon,alt_gps
0,0.1,-0.05,10.0,0.0,0.0,0.0,101325,50.0,25.3,45.2,0.0,0.0,-23.5521,-46.6333,52.3
50,-0.2,0.15,10.2,-0.001,0.001,0.002,101320,49.96,25.3,45.2,-0.08,0.0024,-23.5521,-46.6333,52.3
...
```

---

## Continuous Integration (Future)
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

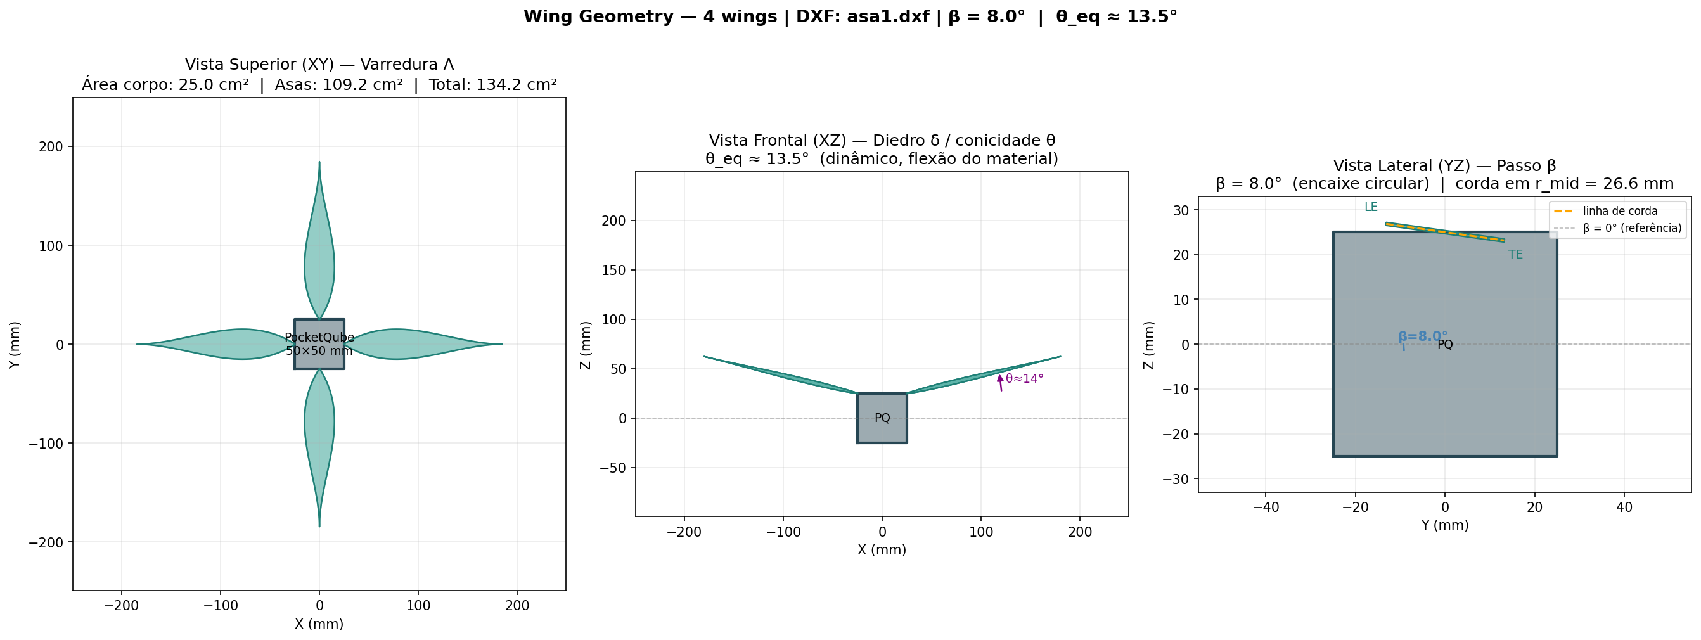
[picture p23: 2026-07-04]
docs/mission-report/figures/fig_test1_geometry.png

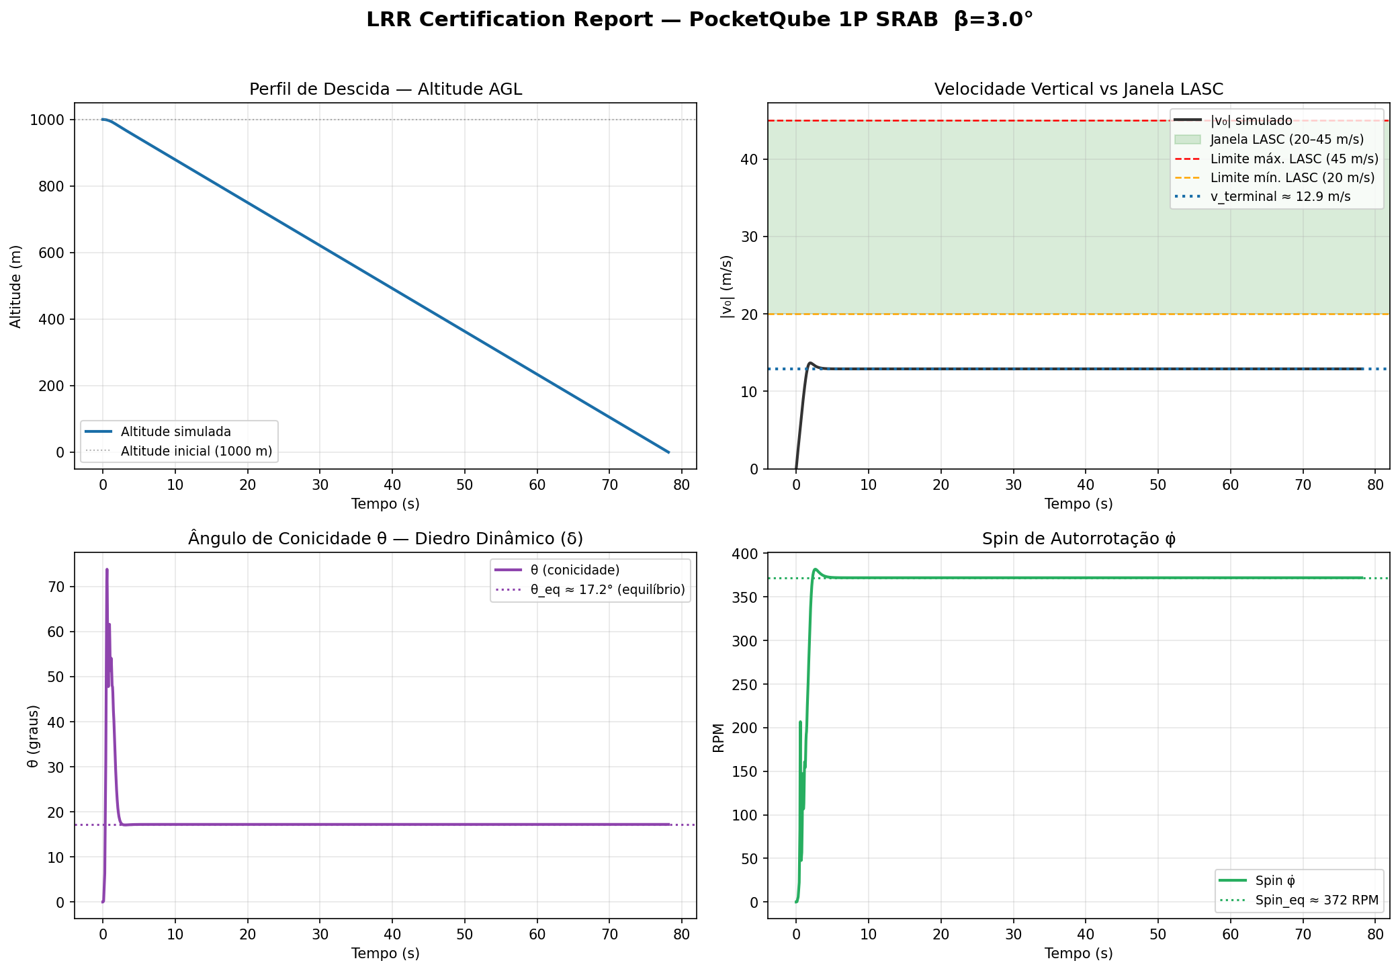
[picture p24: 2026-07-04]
docs/mission-report/figures/fig_test3_sim.png

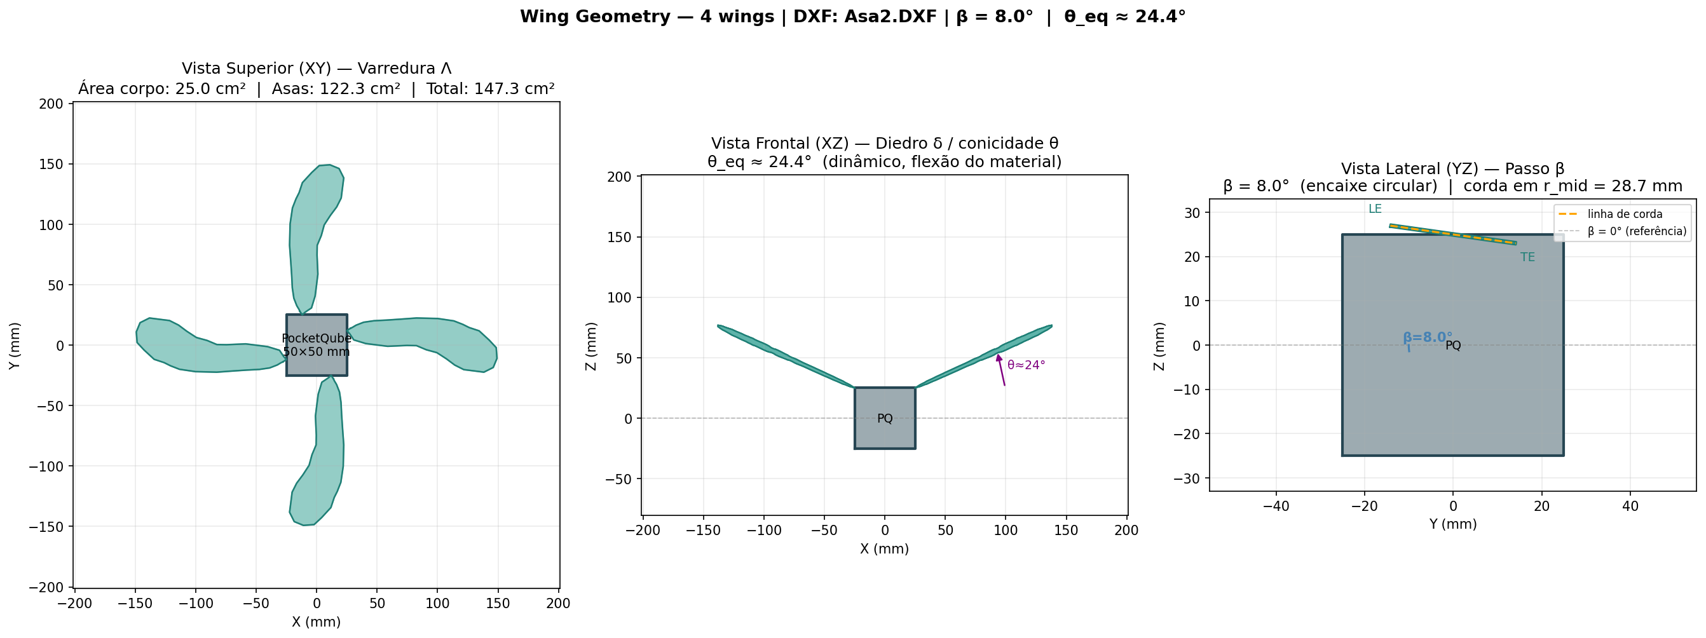
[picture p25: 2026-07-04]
docs/mission-report/figures/fig_test2_geometry.png

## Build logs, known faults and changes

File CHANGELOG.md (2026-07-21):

# Changelog

All notable changes to this project will be documented in this file.

The format is based on [Keep a Changelog](https://keepachangelog.com/en/1.0.0/),
and this project adheres to [Semantic Versioning](https://semver.org/spec/v2.0.0.html).

## [Unreleased]

### Added

- Full project documentation in English (Doxygen on all .h/.cpp/.ino files)
- `docs/software.md` — software architecture and data flow documentation
- `docs/hardware.md` — hardware specifications, pinout, and wiring
- `docs/firmware.md` — build, upload, and testing guide
- `docs/flowchart.md` — Mermaid system flowcharts
- `docs/README.md` — documentation index
- `CHANGELOG.md` — project changelog following Keep a Changelog

### Changed

- All Doxygen comments translated from Portuguese to English
- `README.md` fully translated to English with restructured content
- AGENTS.md conventions updated to English documentation standard

## [1.1.0] - 2026-XX-XX

### Added

- LittleFS logging support with USE_LITTLEFS compile flag
- Integrated validation with lib/calc (NaN and range checks)
- BME280/BMP280 and ICM-20602 support

### Changed

- Pin adjustments and driver refinements
- Standardized CSV format for post-flight analysis

### Removed

- Legacy items from previous project version

## [1.0.0] - 2026-01-27

### Added

- Initial release
- BMP280 barometric sensor support
- ICM-20602 IMU support
- GPS NEO-8M integration
- LoRa telemetry (RFM95W)
- LittleFS data logging
- Hardware validation sketches (test_hardware/)
- Wing analysis study (extras/wing-analysis/)
- Architecture Decision Records (docs/adr/)

[Unreleased]: https://github.com/team100/satellite/compare/v1.0.0...HEAD
[1.0.0]: https://github.com/team100/satellite/releases/tag/v1.0.0

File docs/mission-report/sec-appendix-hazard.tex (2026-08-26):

\textbf{\hfill\break
}

\textbf{Hazard Analysis Appendix}

The following hazards were identified and mitigated by design and/or
process, covering personnel safety during integration, launch and
recovery operations:

\subsection{Hazard 1 — Battery thermal runaway}

\begin{itemize}
\item \textbf{Phase:} Flight.
\item \textbf{Assessment:} A Li-Ion cell can enter thermal runaway
  under overcharge, overdischarge, short-circuit or overcurrent
  conditions, potentially damaging the payload or the launch vehicle.
\item \textbf{Mitigation (design):} BMS with multiple protections
  (overcharge, overdischarge, short-circuit, overcurrent); battery
  cell cycle testing before integration.
\item \textbf{Mitigation (process):} battery charged only with
  approved charger, monitored during pre-launch operations; RBF pin
  cuts all energy during integration and transport.
\end{itemize}

\subsection{Hazard 2 — Stored energy during integration}

\begin{itemize}
\item \textbf{Phase:} Integration and pre-launch.
\item \textbf{Assessment:} a satellite that is accidentally powered
  while inside the deployer can transmit RF, heat up or actuate
  unexpectedly during handling.
\item \textbf{Mitigation (design):} 2 independent kill switches
  (SW1/SW2) in series with the power rail keep the satellite fully
  powered off during integration; RBF pin (SW3) cuts all energy.
\item \textbf{Mitigation (process):} pre-integration verification
  procedure checks kill switch activation; RBF removed only after the
  satellite is installed in the deployer.
\end{itemize}

\subsection{Hazard 3 — Sharp edges of SRAB wings}

\begin{itemize}
\item \textbf{Phase:} Integration and recovery.
\item \textbf{Assessment:} ABS wing edges can cause cuts during
  handling or during the recovery of the landed satellite.
\item \textbf{Mitigation (design):} rounded leading edges on the
  final geometry; wing covers (stowed) during integration.
\item \textbf{Mitigation (process):} handling gloves during
  integration; recovery team briefed on wing handling.
\end{itemize}

\subsection{Hazard 4 — RF interference with other teams}

\begin{itemize}
\item \textbf{Phase:} Flight (telemetry).
\item \textbf{Assessment:} Simultaneous LoRa transmissions from other
  teams on adjacent channels can degrade the telemetry link.
\item \textbf{Mitigation (design):} dedicated packet protocol with
  team ID; 915 MHz channel reservation; local storage as data backup
  (LoRa is support, not mission).
\end{itemize}

\subsection{Hazard 5 — Uncontrolled descent}

\begin{itemize}
\item \textbf{Phase:} Recovery.
\item \textbf{Assessment:} In the event of SRAB deployment failure,
  the satellite would descend ballistically, with impact energy
  sufficient to damage property or persons.
\item \textbf{Mitigation (design):} passive deployment with no
  actuators (validated in 2 drop-test campaigns); geometric
  redundancy (4 wings); impact energy within LASC limits in the
  nominal case.
\item \textbf{Mitigation (process):} launch site clearance per LASC
  rules; recovery team positioned per the simulated impact point.
\end{itemize}

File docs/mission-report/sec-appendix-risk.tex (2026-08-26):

\textbf{\hfill\break
}

\textbf{Risk Assessment Appendix}

Risk is quantified as $R = P \times S$, where $P$ is the failure
probability (1--3) and $S$ the severity (1--3). Failure modes are
organized by mission phase, following the ConOps defined in
Section 2.

\subsection{Risk Matrix (FMECA)}

\begin{center}
{\small
\setlength{\tabcolsep}{3pt}
\begin{tabular}{>{\raggedright\arraybackslash}p{0.5cm}>{\raggedright\arraybackslash}p{6.2cm}>{\raggedright\arraybackslash}p{1.8cm}cccc}
\toprule
\textbf{\#} & \textbf{Failure Mode} & \textbf{Phase} & \textbf{P} & \textbf{S} & \textbf{R} & \textbf{Level} \\
\midrule
1 & SRAB deployment failure (wings do not open) & Ejection & 2 & 3 & 6 & Critical \\
2 & Battery failure (thermal runaway) & Flight & 1 & 3 & 3 & Medium \\
3 & RBF pin does not cut all energy & Pre-launch & 1 & 3 & 3 & Medium \\
4 & LoRa communication loss & Flight & 2 & 2 & 4 & High \\
5 & SD storage failure & Flight & 1 & 3 & 3 & Medium \\
6 & Structural break at launch & Launch & 1 & 3 & 3 & Medium \\
7 & Kill switch not activated & Integration & 1 & 3 & 3 & Medium \\
8 & RF interference (other teams) & Flight & 2 & 2 & 4 & High \\
9 & GPS failure (no fix) & Post-landing & 2 & 1 & 2 & Low \\
10 & SRAB works but satellite lands in inaccessible area & Recovery & 1 & 2 & 2 & Low \\
\bottomrule
\end{tabular}
}
\end{center}

\subsection{Mitigations}

\begin{enumerate}
\item \textbf{SRAB deployment failure (Critical):} passive design
  with no hinges; drop tests \#1 and \#2 validated deployment; 4 wings
  provide geometric redundancy — loss of one wing degrades performance
  but does not prevent recovery.
\item \textbf{Battery thermal runaway:} BMS with multiple protections;
  cell cycle testing.
\item \textbf{RBF pin:} RBF circuit in series with the main power
  rail.
\item \textbf{LoRa loss:} local storage (SD) preserves all flight
  data; LoRa is support, not mission.
\item \textbf{SD failure:} automatic LittleFS fallback on internal
  flash.
\item \textbf{Structural break:} ABS 3D-printed, walls $\geq$1.2 mm;
  load analysis.
\item \textbf{Kill switch:} 2 independent kill switches + pre-integration
  verification.
\item \textbf{RF interference:} dedicated team ID protocol; 915 MHz
  channel reservation.
\item \textbf{GPS failure:} LoRa RSSI triangulation as backup; visual
  search.
\item \textbf{Inaccessible landing:} 3 GPS beacons + buzzer for
  localization.
\end{enumerate}

\subsection{Criticality Discussion}

Failure mode \#1 (SRAB deployment) is treated as critical and is the
main driver of the extensive drop-test campaign. Drop tests \#1 and
\#2 demonstrated that passive deployment works consistently without
actuators. The remaining risk is bounded by the LASC regulatory
limits and by the geometric redundancy of the wing arrangement.

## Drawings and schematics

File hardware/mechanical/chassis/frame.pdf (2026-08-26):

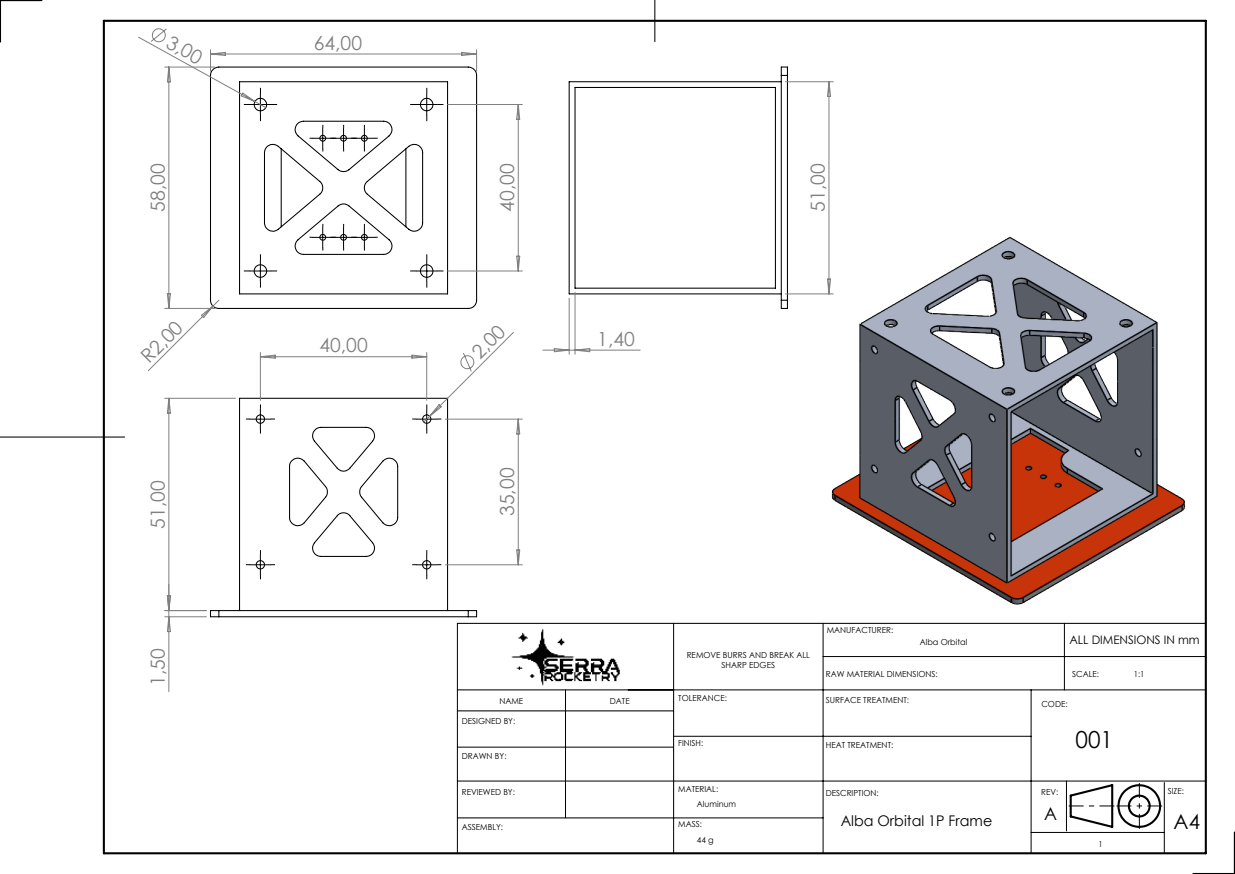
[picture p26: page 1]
SHARP EDGES; SURFACE TREATMENT:; HEAT TREATMENT:; Alba Orbital

ALL DIMENSIONS IN mm MANUFACTURER:

REMOVE BURRS AND BREAK ALL

RAW MATERIAL DIMENSIONS:

DESIGNED BY:

FINISH: MATERIAL: Aluminum

DRAWN BY: REVIEWED BY:

DESCRIPTION:
Alba Orbital 1P Frame

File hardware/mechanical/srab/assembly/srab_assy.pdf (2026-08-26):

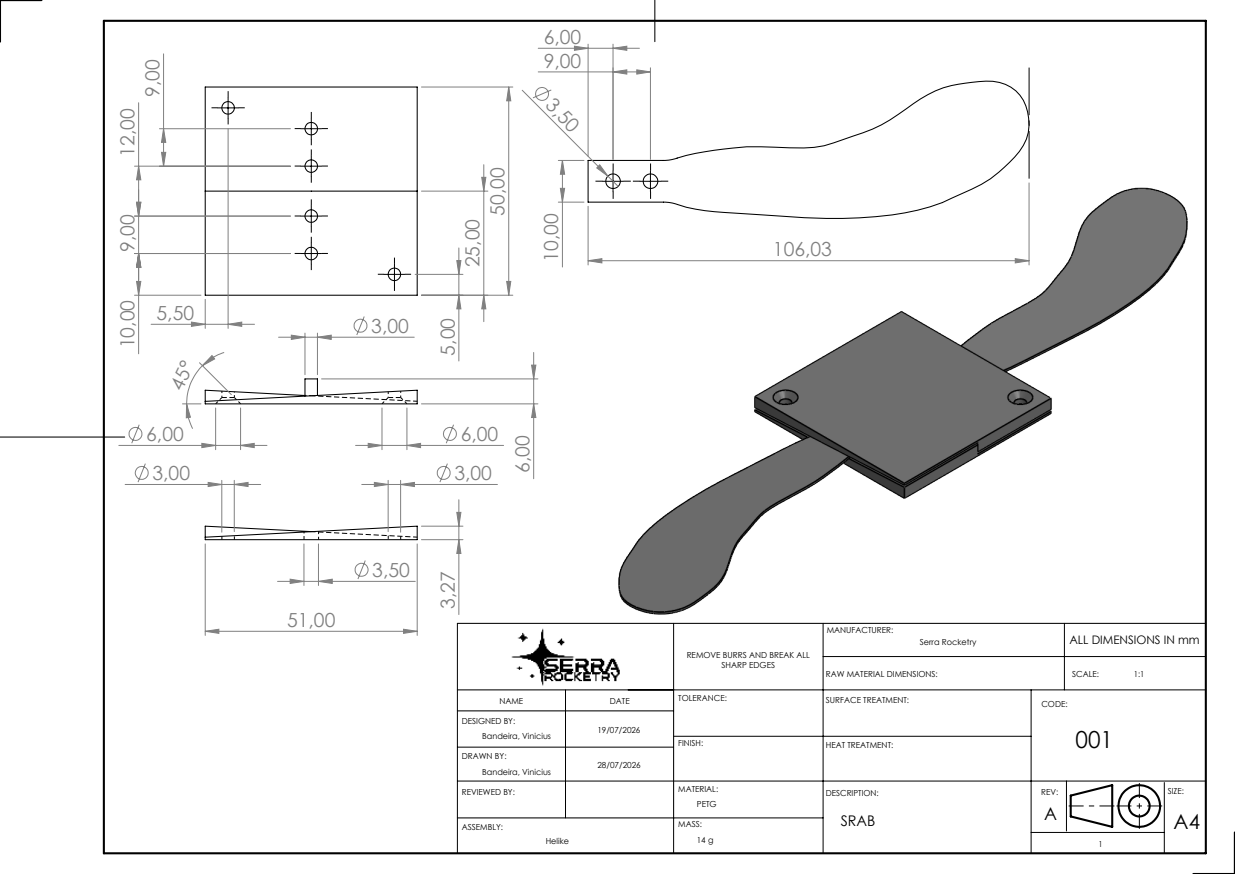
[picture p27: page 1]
SHARP EDGES; SURFACE TREATMENT:; HEAT TREATMENT:; Serra Rocketry

ALL DIMENSIONS IN mm MANUFACTURER:

REMOVE BURRS AND BREAK ALL

RAW MATERIAL DIMENSIONS:

DESIGNED BY: Bandeira, Vinicius | 19/07/2026

FINISH: MATERIAL: PETG

DRAWN BY: Bandeira, Vinicius REVIEWED BY: | 28/07/2026

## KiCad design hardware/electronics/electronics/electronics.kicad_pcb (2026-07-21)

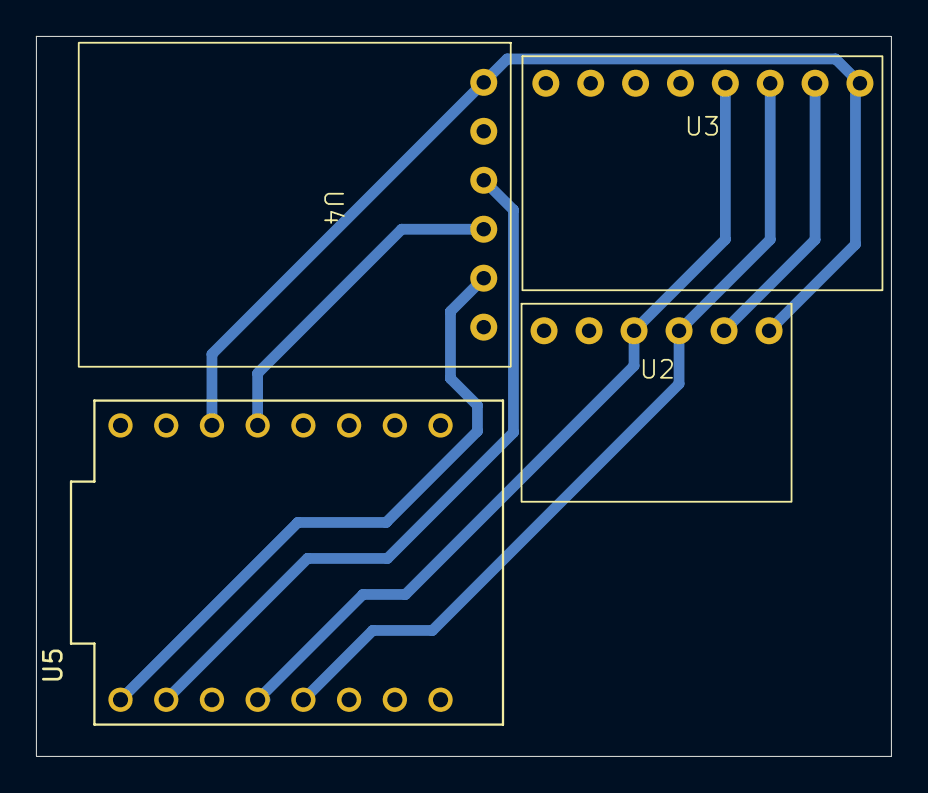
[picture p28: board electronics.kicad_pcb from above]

Board: 2 copper layers, 47.5 x 40.0 mm, 4 parts (0 on the bottom side), 8 nets.

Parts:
U2: BME280
U3: ICM-20602
U4: SD Card mini module
U5: ESP32-C3 SUPERMINI; MODULE_ESP32-C3_SUPERMINI_TH

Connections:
/3.3 VCC: U2.1 (VCC), U3.1 (VCC), U4.1 (VCC), U5.3.3 (3V3)
/CS_SD: U4.2 (CS), U5.10 (GPIO10)
/GND: U2.2 (GND), U3.2 (GND), U4.6 (GND), U5.G (GND)
/MISO: U4.5 (MISO), U5.5 (GPIO5)
/MOSI: U4.3 (MOSI), U5.6 (GPIO6)
/SCK: U4.4 (CLK), U5.4 (GPIO4)
/SCL: U2.3 (SCL), U3.3 (SCL), U5.9 (GPIO9)
/SDA: U2.4 (SDA), U3.4 (SDA), U5.8 (GPIO8)

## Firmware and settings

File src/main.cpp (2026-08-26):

//==============================================================================
// INCLUDES
//==============================================================================

#include <Arduino.h>
#include <Wire.h>
#include <SPI.h>
#include <esp_task_wdt.h>

#include "config.h"
#include "calc/SensorData.h"
#include "calc/DataValidation.h"
#include "calc/VerticalVelocity.h"
#include "sensors/BME280Sensor.h"
#include "sensors/ICM20602Sensor.h"
#include "sensors/GPSSensor.h"
#include "modules/LoRaModule.h"
#include "modules/BuzzerModule.h"
#include "modules/LEDModule.h"
#include "modules/TelemetryModule.h"
#include "modules/FilesystemModule.h"

//==============================================================================
// GLOBAL OBJECTS (static, no heap allocation)
//==============================================================================

static TwoWire i2c_bus = Wire; // alias for Wire
static BME280Sensor g_bme;
static ICM20602Sensor g_icm;
static GPSSensor g_gps;
static BuzzerModule g_buzzer;
static LEDModule g_led;
static TelemetryModule g_telemetry;
static VerticalVelocity g_vz_filter(0.4f);
static DataValidation g_validator(ValidationConfig{VALID_MAX_ACCEL, VALID_MIN_PRESSURE, VALID_MAX_PRESSURE, VALID_MAX_VZ});
static FilesystemModule g_fs;

//==============================================================================
// STATE
//==============================================================================

static uint32_t g_last_sample = 0;
static uint32_t g_last_debug_print = 0;
static bool g_bme_ok = false;
static bool g_icm_ok = false;
static bool g_lora_ok = false;
static uint32_t g_lora_failures = 0;
static uint32_t g_fs_failures = 0;
//==============================================================================
// SETUP
//==============================================================================

void setup() {
    // --- Serial ---
    Serial.begin(SERIAL_BAUD);
    unsigned long serialStart = millis();
    while (!Serial && (millis() - serialStart < 2000)) { ; }
    Serial.println();
    Serial.println(F("========================================"));
    Serial.print(F("  "));
    Serial.print(MISSION_NAME);
    Serial.print(F("  TEAM "));
    Serial.println(TEAM_ID);
    Serial.println(F("  LASC 2026"));
    Serial.println(F("========================================"));
    Serial.println();

    // --- I2C (single begin — initialize global Wire for all sensors) ---
    Wire.begin(I2C_SDA, I2C_SCL);
    delay(100);
    Wire.setClock(400000); // 400kHz Fast Mode
    Serial.println(F("[I2C] Bus initialized (SDA=8, SCL=9, 400kHz)"));

    // --- Buzzer & LED ---
    g_buzzer.begin();
    g_led.begin();
    Serial.println(F("[ACT] Buzzer & LED initialized"));

    // --- BME280 ---
    g_bme_ok = g_bme.begin(Wire, BME280_ADDR);
    if (g_bme_ok) {
        Serial.println(F("[BME] BME280 OK"));
    } else {
        Serial.println(F("[BME] ERROR: BME280 not found!"));
    }

    // --- ICM-20602 ---
    g_icm_ok = g_icm.begin(ICM20602_ADDR, Wire);
    if (g_icm_ok) {
        Serial.println(F("[ICM] ICM-20602 OK"));
    } else {
        Serial.println(F("[ICM] ERROR: ICM-20602 not found!"));
    }

    // --- GPS ---
    g_gps.begin();
    Serial.println(F("[GPS] NEO-8M initialized (9600 baud)"));

    // --- Barramento SPI unico: inicia UMA vez, antes de SD e LoRa ---
    // Ambas as libs (SD/LoRa) chamam SPI.begin() internamente com defaults;
    // a reinicializacao dupla corrompe o estado do periferico no ESP32-C3.
    pinMode(LORA_CS, OUTPUT);  digitalWrite(LORA_CS, HIGH);
    pinMode(SD_CS_PIN, OUTPUT); digitalWrite(SD_CS_PIN, HIGH);
    SPI.begin(LORA_SCK, LORA_MISO, LORA_MOSI);

    // --- LoRa PRIMEIRO: o SD.begin/end reconfigura o periferico SPI e
    // corrompe a comunicacao com o radio se rodar antes. Com o LoRa ja
    // configurado, as transacoes SPI atomicas do SD coexistem sem conflito.
    g_lora_ok = g_telemetry.begin();
    if (g_lora_ok) {
        Serial.println(F("[LORA] RFM95W OK (915MHz)"));
    } else {
        Serial.println(F("[LORA] ERROR: RFM95W not found!"));
    }

    // --- Storage (SD primary, LittleFS fallback) ---
    if (g_fs.begin()) {
        String csv_header = "TEAM_ID,millis,count,altp,temp,umi,p,gp,gr,gy,ap,ar,ay,alt,lat,lon,sat,rssi";
        g_fs.createFile("/telemetry.csv", csv_header);
        Serial.print(F("[FS] Storage: "));
        Serial.println(g_fs.getTypeString());
    } else {
        Serial.println(F("[FS] ERROR: No storage available!"));
    }

    // --- Status summary ---
    Serial.println(F("--- Initialization Summary ---"));
    Serial.print(F("  BME280:    ")); Serial.println(g_bme_ok ? F("OK") : F("FAIL"));
    Serial.print(F("  ICM-20602: ")); Serial.println(g_icm_ok ? F("OK") : F("FAIL"));

    // --- Watchdog (ESP32-C3 TWDT) — init before beeps/blinks ---
    esp_task_wdt_init(WATCHDOG_TIMEOUT_MS * 1000, true);
    esp_task_wdt_add(NULL); // Subscribe current task

    // --- Audio/visual feedback ---
    if (g_bme_ok && g_icm_ok) {
        g_buzzer.playStartup();
        g_led.blink(3, 300);
    } else {
        g_buzzer.playError();
        g_led.blinkFast(10);
    }

    g_last_sample = millis();
    g_last_debug_print = millis();

    Serial.println(F("[SYS] Setup complete. Starting main loop..."));
    Serial.println();
}

//==============================================================================
// LOOP
//==============================================================================

void loop() {
    unsigned long now = millis();

    // --- GPS update (always, to keep parser fresh) ---
    g_gps.update();

    // --- Main loop at sample interval ---
    if (now - g_last_sample < SAMPLE_INTERVAL_MS) {
        return;
    }
    // --- Feed watchdog ---
    esp_task_wdt_reset();

    // --- Update IMU ---
    g_icm.update();

    // --- Collect data ---
    SensorData data;
    g_telemetry.collectData(g_bme, g_icm, g_gps, data);

    // --- Validate data ---
    bool valid = g_validator.isValid(data);

    // --- Calculate Vz (skip first sample — filter has no history) ---
    static bool g_first_sample = true;
    if (valid && !isnan(data.altura)) {
        if (g_first_sample) {
            g_first_sample = false;
            data.vz = NAN;
        } else {
            data.vz = g_vz_filter.update(data.altura, now);
        }
    } else {
        data.vz = NAN;
    }

    // --- Calculate gyroscope magnitude ---
    if (valid) {
        data.mag_giroscopia = sqrtf(data.gx * data.gx + data.gy * data.gy + data.gz * data.gz);
    } else {
        data.mag_giroscopia = NAN;
    }

    // --- Build CSV packet ---
    char packetBuf[160];
    g_telemetry.formatPacket(data, packetBuf, sizeof(packetBuf));
    String packet(packetBuf);

    // --- Transmit ---
    if (!g_telemetry.send(packet)) {
        g_lora_failures++;
        Serial.println(F("[LORA] ERROR: send() failed"));
    }

    // --- Log to storage (LittleFS/SD) ---
    if (!g_fs.appendLine(packet)) {
        g_fs_failures++;
        Serial.println(F("[FS] ERROR: appendLine() failed"));
    }

    // --- Heartbeat LED ---
    g_led.toggle();

    // --- Periodic debug print ---
    if (DEBUG_ENABLED && (now - g_last_debug_print >= DEBUG_PRINT_INTERVAL_MS)) {
        g_last_debug_print = now;
        unsigned long loop_duration = now - g_last_sample;
        Serial.print(F("[DEBUG] Packet #"));
        Serial.print(g_telemetry.getPacketCount());
        Serial.print(F(" | BME:"));
        Serial.print(g_bme_ok ? F("ok") : F("--"));
        Serial.print(F(" ICM:"));
        Serial.print(g_icm_ok ? F("ok") : F("--"));
        Serial.print(F(" LoRa:"));
        Serial.print(g_lora_ok ? F("ok") : F("--"));
        Serial.print(F(" GPS sats:"));
        Serial.print(g_gps.getSatellites());
        Serial.print(F(" | Vz:"));
        Serial.print(data.vz);
        Serial.print(F(" | loop:"));
        Serial.print(loop_duration);
        Serial.print(F("ms | LoRa fails:"));
        Serial.print(g_lora_failures);
        Serial.print(F(" FS fails:"));
        Serial.println(g_fs_failures);
    }
    g_last_sample = now;
}

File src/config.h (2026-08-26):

/**
 * @file config.h
 * @brief Global configuration for the Helike PocketQube satellite (#213 - LASC 2026)
 *
 * CRITICAL CONTEXT: The satellite remains COMPLETELY POWERED OFF (no energy)
 * until the rocket deploys at apogee. Upon power-on, the system is already
 * descending. There is no sleep mode, no liftoff detection.
 *
 * System objectives:
 * 1. On power-up, initialize sensors and LoRa as fast as possible
 * 2. Read sensors and transmit telemetry continuously
 * 3. No FSM, no unnecessary complexity
 *
 * @author Serra Rocketry Team — Mission #213
 * @date 2026
 */

#ifndef CONFIG_H
#define CONFIG_H

#include <Arduino.h>

//==============================================================================
// IDENTIFICATION
//==============================================================================

#define TEAM_ID             "#213"
#define MISSION_NAME        "Helike PocketQube"

//==============================================================================
// PINOUT (ESP32-C3 Super Mini)
//==============================================================================

// I2C bus
#define I2C_SDA             8
#define I2C_SCL             9

// LoRa SPI (RFM95W)
#define LORA_MOSI           6
#define LORA_MISO           5
#define LORA_SCK            4
#define LORA_CS             7
#define LORA_RST            1
#define LORA_DIO0           2

// SD Card SPI (compartilhado com LoRa)
#define SD_CS_PIN           10

// GPS UART (NEO-8M)
#define GPS_RX              20
#define GPS_TX              21

// Actuators
#define LED_PIN             3
#define BUZZER_PIN          0

//==============================================================================
// TIMING
//==============================================================================

#define SERIAL_BAUD         115200
#define GPS_BAUD            9600

// Sample interval (ms) — 200ms = 5Hz
#define SAMPLE_INTERVAL_MS  200

// LoRa transmission interval (ms) — same as sample rate
#define LORA_INTERVAL_MS    200

// GPS read interval (ms)
#define GPS_READ_INTERVAL_MS 1000

// Debug serial print interval (ms)
#define DEBUG_PRINT_INTERVAL_MS 2000

//==============================================================================
// LORA
//==============================================================================

#define LORA_FREQ           915E6           // Americas (Brasil)
#define LORA_SYNC_WORD      0xF3
#define LORA_TX_POWER       20              // dBm maximo
#define LORA_SPREADING      7               // SF7
#define LORA_BANDWIDTH      125E3           // 125kHz

//==============================================================================
// SENSORS
//==============================================================================

// BME280 barometric sensor
#define BME280_ADDR         0x76
#define BME280_SEALEVEL_HPA 1013.25f

// ICM-20602 IMU
#define ICM20602_ADDR       0x69
#define ACCEL_SCALE         16.0f           // ±16g
#define GYRO_SCALE           2000.0f         // ±2000°/s

// Data validation limits
#define VALID_MAX_ACCEL     (20.0f * 9.80665f)  // ±20g maximum
#define VALID_MIN_PRESSURE  30000.0f            // Pa
#define VALID_MAX_PRESSURE  120000.0f           // Pa
#define VALID_MAX_VZ        200.0f              // m/s

//==============================================================================
// WATCHDOG
//==============================================================================

#define WATCHDOG_TIMEOUT_MS 5000            // 5 seconds

//==============================================================================
// DEBUG
//==============================================================================

#define DEBUG_ENABLED      1
#define LORA_DEBUG_LOGS     0

// LittleFS: enable for flash logging (hardware test / bench)
// In real flight, disable to save power / flash wear
#define USE_LITTLEFS       1

#endif // CONFIG_H

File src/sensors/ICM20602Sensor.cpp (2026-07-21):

/**
 * @file ICM20602Sensor.cpp
 * @brief ICM-20602 inertial sensor driver implementation
 *
 * Implements raw I2C register access for the ICM-20602, including
 * wake-up, WHO_AM_I verification, range configuration, and data
 * acquisition for accelerometer and gyroscope.
 *
 * @author Serra Rocketry Team — Mission #213
 * @date 2026
 */

#include "ICM20602Sensor.h"

ICM20602Sensor::ICM20602Sensor()
    : _wire(nullptr), _ready(false), _hasNewData(false),
      _ax(0.0f), _ay(0.0f), _az(0.0f),
      _gx(0.0f), _gy(0.0f), _gz(0.0f) {
}

bool ICM20602Sensor::begin(uint8_t addr, TwoWire &wire) {
  _addr = addr;
  _wire = &wire;

  // Wake up the sensor: clear sleep bit (bit 6) in PWR_MGMT_1 (0x6B)
  _wire->beginTransmission(_addr);
  _wire->write(0x6B);
  _wire->write(0x00); // Wake up, disable sleep
  if (_wire->endTransmission() != 0) {
    return false;
  }

  // Check WHO_AM_I
  if (!testConnection()) {
    return false;
  }

  // Configure ranges:
  // GYRO_CONFIG (0x1B): FS_SEL = 3 → ±2000°/s (0x18 = 0b00011000)
  _wire->beginTransmission(_addr);
  _wire->write(0x1B);
  _wire->write(0x18);
  if (_wire->endTransmission() != 0) {
    _ready = false;
    return false;
  }

  // ACCEL_CONFIG (0x1C): AFS_SEL = 3 → ±16g (0x18 = 0b00011000)
  _wire->beginTransmission(_addr);
  _wire->write(0x1C);
  _wire->write(0x18);
  if (_wire->endTransmission() != 0) {
    _ready = false;
    return false;
  }

  _ready = true;
  return true;
}

void ICM20602Sensor::update() {
  if (!_ready) return;

  // Read accelerometer data (0x3B to 0x40)
  _wire->beginTransmission(_addr);
  _wire->write(0x3B);
  _wire->endTransmission(false);
  if (_wire->requestFrom(_addr, 6) != 6) {
    return; // I2C error: data unavailable
  }
  int16_t ax_raw = (_wire->read() << 8) | _wire->read();
  int16_t ay_raw = (_wire->read() << 8) | _wire->read();
  int16_t az_raw = (_wire->read() << 8) | _wire->read();

  // Read gyroscope data (0x43 to 0x4A)
  _wire->beginTransmission(_addr);
  _wire->write(0x43);
  _wire->endTransmission(false);
  if (_wire->requestFrom(_addr, 6) != 6) {
    return; // I2C error: data unavailable
  }
  int16_t gx_raw = (_wire->read() << 8) | _wire->read();
  int16_t gy_raw = (_wire->read() << 8) | _wire->read();
  int16_t gz_raw = (_wire->read() << 8) | _wire->read();

  // Convert to physical units
  _ax = ax_raw * ACCEL_FACTOR;
  _ay = ay_raw * ACCEL_FACTOR;
  _az = az_raw * ACCEL_FACTOR;
  _gx = gx_raw * GYRO_FACTOR;
  _gy = gy_raw * GYRO_FACTOR;
  _gz = gz_raw * GYRO_FACTOR;

  _hasNewData = true;
}

float ICM20602Sensor::getAx() const { return _ax; }
float ICM20602Sensor::getAy() const { return _ay; }
float ICM20602Sensor::getAz() const { return _az; }
float ICM20602Sensor::getGx() const { return _gx; }
float ICM20602Sensor::getGy() const { return _gy; }
float ICM20602Sensor::getGz() const { return _gz; }

void ICM20602Sensor::wakeUp() {
  // Already done in begin()
}

/**
 * @brief Tests I2C connection by reading WHO_AM_I register
 * @return true if WHO_AM_I matches expected value (0x12 for ICM-20602)
 */
bool ICM20602Sensor::testConnection() {
  _wire->beginTransmission(_addr);
  _wire->write(0x75); // WHO_AM_I register
  _wire->endTransmission(false);
  _wire->requestFrom(_addr, 1);
  if (_wire->available() != 1) {
    return false;
  }
  uint8_t who = _wire->read();
  return (who == 0x12); // ICM-20602 expected ID
}

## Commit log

2026-04-08 [WINGS] Add reverse DXF analysis script
    - New script analisar_dxf.py: extract wing geometry from DXF and run descent simulations
    - Supports SPLINE, POLYLINE, and LINE entities from CAD files
    - Analyzes chord distribution and calculates optimal configurations
    - Outputs geometry plots, JSON data, and text reports
    Tested with Asa2.DXF:
    - Extracts 125mm radius wing with complex geometry
    - Finds optimal config: 6×125mm at v₀=7.12 m/s (18% better than 16cm baseline)
    - Cabe dobrado: Yes ✓
    This enables iterative design: CAD → DXF → Analysis → Optimization
2026-04-08 [WINGS] Fix DXF analysis: proper spline interpolation and area calculation
    Fixed two critical issues:
    1. Contour interpolation: Use scipy.interpolate.splprep/splev to properly
    interpolate spline curves instead of using raw control points
    Result: 34 points → 340 smooth points ✓
    2. Area calculation: Use Polygon (Shapely) with Shoelace formula for
    accurate area instead of simple trapezoid integration
    Result: 3.43 cm² → 30.76 cm² ✓ (now matches CAD measurement 30.47cm²)
    - Contour now smooth (no zigzag artifacts)
    - Area error reduced to 0.9%
    - Simulations now trustworthy
    Geometry extracted:
    - Raio: 124.4mm
    - Corda máxima: 68mm @ 87% do raio
    - Área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
2026-04-08 [DOCS] Add DXF analysis documentation
    Complete guide for reverse workflow: CAD → DXF → Analysis
    Includes:
    - Workflow diagram
    - Usage instructions
    - Algorithm explanation
    - Configuration parameters
    - Troubleshooting guide
    - Example scenarios
    Quick reference for users who want to iterate wing designs in CAD
2026-04-08 fix: Corrigir física da simulação de descida
    - Implementar fórmula aerodinâmica correta: v = √(2*m*g / (ρ*Cd*A))
    - Remover fórmula empírica incorreta que não respondia à área
    - Aceitar area_real_cm2 como parâmetro (extraída do DXF via Shapely)
    - Remover recálculo duplicado de área por integração
    - Adicionar constantes físicas explícitas (ρ_ar, Cd)
    - Validação: aumentar área 9x reduz v_terminal em 66.5% (√9 ≈ 1/3)
    Mudanças:
    - simular_descida() agora: def simular_descida(R, corda_func, area_real_cm2, ...)
    - Removido clamp máximo de 30 m/s (permitir valores realistas para asas pequenas)
    - Documentação atualizada com histórico de correção
2026-04-08 feat: Adicionar arrasto da área frontal do PocketQube
    - Adicionar área frontal do PocketQube (50×50 mm = 25 cm²) ao cálculo
    - Fórmula: A_total = n_asas × area_asa + area_frontal_pq
    - Impacto: velocidade reduz ~6-16% dependendo do número de asas
    - Validação com Asa2:
    * 2 asas: 32.78 → 27.64 m/s (-15.7%)
    * 4 asas: 23.31 → 21.25 m/s (-8.8%)
    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
    [13_30_11-Dados.csv, Asa2.DXF, asa_16cm.dxf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]
2026-04-08 fix: Atualizar estudos de asas com fórmula aerodinâmica correta
    - Atualizar estudo_asa_2p.py com v_terminal aerodinâmica (v = √(2mg/ρCdA))
    - Atualizar estudo_asa_helike.py com v_terminal aerodinâmica
    - Adicionar área frontal do PocketQube (25 cm²) em ambos
    - Corrigir ordem de operações em cálculo de massa por asa (helike.py)
    - Documentar unidades claramente (R em metros)
    - Adicionar aviso sobre calibração de área (modelo 0.03*R² subestima ~4x)
    Descoberto:
    - Fórmula de área subestima área real por ~4x
    - Causa velocidades calculadas ~2x maiores que realistas
    - Conclusões sobre viabilidade podem estar incorretas
    Recomendação:
    - Usar dados reais de asas (extraída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
2026-04-08 test: Teste 2 - Sensores unificados e BMP280 com SPIFFS
    Adicionados arquivos de teste para integração de sensores:
    - sensores_unificado.ino: Integra ICM20602 (acelerômetro/giroscópio) + BMP280 (pressão/altura)
    - bmp280_spiffs.ino: Teste isolado de BMP280 com salvamento em SPIFFS
    Status do Teste 2 (08/04/2026):
    - RESULTADO: Satélite perdido durante o voo
    - PROBLEMA: Telemetria não funcionou - não conseguimos ativar a comunicação LoRa
    - OBSERVAÇÃO: Satélite foi testado sem telemetria, apenas com sensores
    - PRÓXIMOS PASSOS: Debugar sistema de telemetria LoRa antes do próximo teste
2026-04-09 fix: Ajustar I2C no ESP32-C3 e adicionar checklist de bancada
    [icm20602.ino]
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2026-04-09 docs: adicionar detalhes sobre código embarcado dos testes de queda
    Documentar progresso em desenvolvimento:
    - Eletrônica: Circuito I2C com ICM-20602 + BMP280 testado e validado
    - Código embarcado: 690 linhas em 5 arquivos Arduino com testes completos
    * sensores_unificado.ino: Integração completa com logging em CSV
    * Detecção automática de sensores, reset I2C, tratamento de erros
    * Leitura raw com conversão para unidades físicas (m/s², rad/s, Pa, m)
    * Suporte a ESP32 e ESP32-C3 com detecção automática
    - Pinagem otimizada: GPIO 8 (SDA), GPIO 9 (SCL) para ESP32-C3
    - Próximos passos: Integração com SD Card, GPS e servo motor
    Fase 1 (freio aerodinâmico) agora inclui se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
2026-04-09 fix: Reconciliar inconsistências no plano de testes de queda e harmonizar documentação
    - Corrigir conflito v_terminal (23.31 m/s vs -5 m/s): esclarecer que testes em 10m NÃO atingem regime terminal
    - Redefinir metodologia de análise: usar Vz_médio em janela estável vs Vz_min (mais robusto para quedas curtas)
    - Remover todas referências a BMP280/AHT10/MPU6050 do README (agora BME280/ICM-20602 em Fases 4-6)
    - Adicionar checklist crítico de validação de hardware: níveis lógicos GPS TX, alimentação dual 3.3V/5V, pull-ups I2C
    - Atualizar tabela de testes com valores reais de simulação do Asa2_relatorio.txt
    - Melhorar documentação de pinagem e protocolos de teste
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2026-05-12 reorganizar diretorios test/ e extras/ e migrar SPIFFS para LittleFS
    - test/: dividido em docs/, sensor/, integration/, storage/
    - extras/wing-analisys/: src/, geometry/, results/, docs/, guides/
    - SD_SPIFFS_fallback migrado para sd_littlefs_fallback (LittleFS)
    - bmp280_spiffs renomeado para bmp280_littlefs
    - paths atualizados em todos os documentos afetados
    [Asa2.DXF, asa1.dxf]
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2026-06-09 Fix wing-analisys: corrigir output_dir do script e organizar arquivos
    - Corrigir default output_dir do script de src/ para results/
    - Mover arquivos de output de src/ para results/
    - Criar pasta test_3_asa3/ com dados do Asa3.DXF
    - Organizar geometry_views.png e trajectory.csv em test_3_asa3/
    - Estrutura limpa: src/ só tem o script, results/ tem pastas por teste
    [samara_pq_trajectory.csv]
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2026-06-24 Revert "rocketpy integration"
    This reverts commit 52f25b94c023dc15a0fb60d644f114ca0d5aef4b.
    [mc_srab_200.csv, samara_pq_trajectory.csv]
2026-06-24 Reapply "rocketpy integration"
    This reverts commit 802c1b2bb8e844ed6fbd85728b67b4cd0f4489f9.
    [mc_srab_200.csv, samara_pq_trajectory.csv]
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2026-06-24 refactor: adiciona headers Doxygen e expande SensorData no lib/calc
    - ApogeeDetection.h: header Doxygen completo, pragma once, endif
    - DataValidation.h: header Doxygen, pragma once, endif
    - VerticalVelocity.h: header Doxygen, pragma once, endif, corrige formula EMA
    - SensorData.h: adiciona campos temperatura, umidade, lat, lon, altura_gps, satellites
    - test_validation.cpp: atualiza makeData para novos campos, ajusta thresholds
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2026-06-24 feat: adiciona firmware do satellite (main, sensores, modulos)
    - main.cpp: setup + loop com BME280, ICM-20602, GPS, LoRa, Serial
    - config.h: pinos, thresholds, intervalos
    - sensors/: BME280Sensor, ICM20602Sensor, GPSSensor
    - modules/: LoRaModule, BuzzerModule, LEDModule, TelemetryModule, FilesystemModule
    [BuzzerModule.cpp, FilesystemModule.cpp]
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2026-07-04 docs: corrige caminhos e padroniza documentacao do SRAB
    - Renomeia extras/wing-analisys/ -> extras/wing-analysis/ em 23 ocorrencias
    (README.md, test_hardware/docs/, .opencode/skills/)
    - Atualiza arvore de diretorios no README.md (guides/ removido)
    - Converte CLI de code block para tabela em scripts.md
    - Remove sintaxe LaTeX \citep{} de teoria.md
    - Adiciona entrada v1.2.0 no CHANGELOG.md
2026-07-04 style: aplica ruff lint e format nos scripts do SRAB
    - Corrige 9x E702 (statements multiplos em uma linha)
    - Remove variavel nao utilizada s em srab_field_analysis.py
    - Aplica ruff format em 4 arquivos
    [srab_field_analysis.py]
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2026-07-21 fix: correct pinout per schematic, fix I2C init, add USB CDC, BMP280 fallback, LEDC buzzer
    Pinout corrections (source: schematic):
    - LORA_CS=7(NSS), LORA_RST=1(RESET), LORA_DIO0=2 (was 10/10/3)
    - SD_CS=10(CS_SD) (was 5, which conflicted with SPI MISO)
    - LED=3, BUZZER=0 (was swapped)
    I2C fix: removed resetI2C() which toggled SDA/SCL via pinMode/digitalWrite
    and broke the TwoWire peripheral. Single Wire.begin() now.
    USB CDC: added ARDUINO_USB_MODE=1 and ARDUINO_USB_CDC_ON_BOOT=1
    to build_flags so Serial.println() appears via USB.
    BMP280 fallback: try BME280 first; if not found, use BMP280.
    getHumidity() returns NAN on BMP280 (no humidity sensor).
    Buzzer: replaced tone() with ledcSetup/ledc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
    [BuzzerModule.cpp, FilesystemModule.cpp, bme280.ino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]
2026-07-21 docs: update opencode skills with corrected pinout and ESP32-C3 pitfalls
    - firmware-developer: DIO0=2, RST=1, LoRa CS=7 (was 3/4/10)
    - code-reviewer, test-engineer: removed emojis and PT strings
    - SKILLS_INDEX.md: removed emojis from titles
    - All skills: consistent with current hardware pinout
2026-07-22 fix: call g_icm.update() in main loop so IMU data is actually read
    ICM-20602 uses a cached-value pattern: update() reads the sensor
    registers and converts to physical units; getAx/getGy/etc return
    cached values. update() was never called in loop(), causing all
    accelerometer and gyroscope readings to be stuck at zero.
    [main.cpp]
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2026-07-22 chore: remove dead code, clean up, add node_modules to gitignore
    - Removed unused src/utils/i2c_helper.h (resetI2C was already removed)
    - Removed src/sensors_disabled/ (legacy GPSModule, disabled via build_src_filter)
    - Added node_modules/ to .gitignore (opencode had 61MB tracked)
    - Cleaned KiCad temporary files in electronics submodule
2026-07-22 fix: use digitalWrite for active buzzer (no PWM/LEDC needed)
    Active buzzer has built-in oscillator - just needs DC HIGH/LOW.
    Removed ledcSetup/ledcAttachPin/ledcWrite, replaced with simple
    pinMode/digitalWrite.
    [BuzzerModule.cpp]
2026-07-22 docs: update buzzer type to active (digitalWrite, no PWM)
    - hardware.md: active buzzer, GPIO (digitalWrite), LEDC bug note updated
    - firmware.md: LEDC bug workaround corrected for active buzzer
    - software.md: BuzzerModule description updated
    [electronics.kicad_sch]
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2026-07-28 feat: add SRAB vs parachute comparison, MC analysis, and wing geometry plot to Dedalo simulation notebook
    - New section 9: SRAB vs Parachute comparison (altitude, descent velocity,
    horizontal drift, summary table) — all graphs in English
    - New section 10.1: Monte Carlo sensitivity (100 iterations, 4 stochastic
    params: mass, beta, cd0, f_factor) with histograms and CSV export
    - Wing geometry orthogonal views (top/front/side) in English labels
    - All comparison plot labels, titles, legends and table headers translated
    to English
    [mc_srab_dedalo.csv]
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2026-08-06 docs: reframe mission report as SRAB technology development
    - Introduction: LASC as the flight-test plan for the SRAB, not a
    one-off competition; each ConOps arc exercises one stage of the
    technology (three-filter review, Dédalo launch vehicle context)
    - Architecture: ConOps rewritten as development arcs (boost/ejection/
    descent/post-landing), SRAB = Asa3 two-wing configuration, single
    polling loop firmware (not FSM)
    - Conclusions: development framing, honest pendencies (Test 4, PCB,
    structure), parachute comparison (36% shorter descent, 36% less drift)
2026-08-06 docs: add SRAB-vs-parachute and trajectory map figures, translate plot labels
    - figures/fig_srab_vs_parachute.png: benchmark bars + summary table
    from the report comparison values (13.33/8.48 m/s, 111.4/174.6 s,
    131.2/204.6 m, 17.8/7.2 J) - NOT the notebook figure (drift mismatch)
    - figures/fig_trajectory_map.png: satellite view of the descent from
    mapa_deploy_srab.html render (1280x633, ESRI tiles)
    - sec-computational-simulation.tex: include both figures; captions of
    fig_asa3_lrr and fig_test2_sim no longer claim the 20-45 window
    - wing-analysis src: PT->EN plot labels/titles (T2.3 image language)
    [srab_field_analysis.py]
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2026-08-24 fix: align CSV header with 18-field protocol, remove unused BUTTON_PIN
    - CSV header now matches TelemetryModule formatPacket (ap/ar/ay added)
    - Drop BUTTON_PIN define colliding with LORA_DIO0 (GPIO2)
    - Update AGENTS.md packet format: 18 fields -> 24 (per protocol.md v2.0)
    [config.h, main.cpp]
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2026-08-26 fix: correct endPacket() success check in LoRaModule::send
    sandeepmistry LoRa returns 1 on success, 0 on failure. The inverted
    check reported every successful TX as an error since module creation.
    [LoRaModule.cpp]
2026-08-26 fix: single SPI init, LoRa-first boot order, robust SD handling
    - Initialize SPI once in setup() with CS pins HIGH before any library
    - Boot LoRa before storage: SD mount corrupts radio config if done first
    - Remove SD.end() retry path (tears down shared SPI peripheral)
    - Send 74+ wake-up clocks with CS high before SD mount
    - Degrade to LittleFS at runtime after 5 consecutive appendLine failures
    - Move SD_CS_PIN to config.h (was private constant in FilesystemModule)
    [FilesystemModule.cpp, config.h, main.cpp]
2026-08-26 docs: ADR-005 SPI bus sharing rules, bench findings in known issues
    - ADR-005: single SPI init, LoRa-first order, no SD.end(), verification
    sequence for pre-flight checks
    - hardware.md: shared SPI pitfalls, SD FAT32/wake-up notes, wiring
    guidance, sandeepmistry endPacket() API note
    - software.md: load-bearing boot order, config.h pin table update
2026-08-26 fix: sd_littlefs_fallback test sketch pinout and declaration order
    - SD CS GPIO5 -> GPIO10, SPI pins per current schematic (SCK=4/MISO=5/MOSI=6)
    - Move file_path declaration before first use (build error)
    [sd_littlefs_fallback.ino]
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2026-08-26 docs: fix LED pin GPIO3 in software.md, add BMP280 lib to README deps
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2026-08-26 data: refresh landing artifacts (GFS run @ 2026-08-26 04:07 UTC)
    - apogeu, drift SRAB, area de impacto
    - 3D trajectory + top-down GeoJSON
    - triggered by: push
    - previous: @ adde5ef
2026-08-26 data: refresh landing artifacts (GFS run @ 2026-08-26 04:12 UTC)
    - previous: @ f44d3a9
    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
2026-08-26 data: refresh landing artifacts (GFS run @ 2026-08-26 04:26 UTC)
    - triggered by: workflow_dispatch
    - previous: @ 75463c7
    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
2026-08-26 data: refresh landing artifacts (GFS run @ 2026-08-26 04:32 UTC)
    - previous: @ fe15d17
    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
2026-08-26 data: refresh landing artifacts (GFS run @ 2026-08-26 04:35 UTC)
    - previous: @ 5d56246
    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
2026-08-26 ci: rebase before pushing landing artifacts to avoid run race
2026-08-26 data: refresh landing artifacts (GFS run @ 2026-08-26 04:46 UTC)
    - previous: @ 652ac85
    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
2026-08-26 data: refresh landing artifacts (GFS run @ 2026-08-26 04:47 UTC)
    - previous: @ a56a56c
    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
2026-08-26 data: refresh landing artifacts (GFS run @ 2026-08-26 04:50 UTC)
    - previous: @ 2e885f7
    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
2026-08-26 data: refresh landing artifacts (GFS run @ 2026-08-26 07:28 UTC)
    - triggered by: schedule
    - previous: @ 586aa8f
    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
2026-08-26 fix: update launch date to Sep 4 in simulation script and landing countdown
2026-08-26 ci: rebase against current branch to avoid PR self-conflict
2026-08-26 data: refresh landing artifacts (GFS run @ 2026-08-26 11:15 UTC)
    - previous: @ da0a049
    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
2026-08-26 data: refresh landing artifacts (GFS run @ 2026-08-26 11:24 UTC)
    - previous: @ a198bed
    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
2026-08-26 data: refresh landing artifacts (GFS run @ 2026-08-26 11:42 UTC)
    - previous: @ 40b8f5f
    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
2026-08-26 data: refresh landing artifacts (GFS run @ 2026-08-26 13:15 UTC)
    - previous: @ a6916fd
    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
2026-08-26 data: refresh landing artifacts (GFS run @ 2026-08-26 13:19 UTC)
    - previous: @ 992e779
    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
2026-08-26 data: refresh landing artifacts (GFS run @ 2026-08-26 13:36 UTC)
    - previous: @ ccfd1e2
    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
2026-08-26 data: refresh landing artifacts (GFS run @ 2026-08-26 20:59 UTC)
    - previous: @ 8ab03ef
    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
2026-08-27 data: refresh landing artifacts (GFS run @ 2026-08-27 10:11 UTC)
    - previous: @ 224ede8
    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
2026-08-27 data: refresh landing artifacts (GFS run @ 2026-08-27 22:31 UTC)
    - previous: @ 91e4772
    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
2026-08-28 feat: add vehicle spec cards with motor info and impact coords to landing page
    - extract_vehicle_info(): Dedalo (mass, motor impulse/thrust/burn from
    RocketPy objects) + Helike specs (avionics, radio, SRAB) into
    landing.json vehicles block, defensive property access
    - landing page: two vehicle spec cards under stage legend, populated
    from landing.json with fallback for missing fields
    - parachute_descent and srab_descent now carry impact_lat/lon (same
    geodesic approximation as the GeoJSON)
    - impact coords shown on both vehicle cards
2026-08-28 data: refresh landing artifacts (GFS run @ 2026-08-28 03:49 UTC)
    - previous: @ 1c12404
    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
2026-08-28 data: refresh landing artifacts (GFS run @ 2026-08-28 04:16 UTC)
    - previous: @ 043ae81
    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
2026-08-28 data: refresh landing artifacts (GFS run @ 2026-08-28 04:36 UTC)
    - previous: @ 081dda1
    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
2026-08-28 data: refresh landing artifacts (GFS run @ 2026-08-28 04:42 UTC)
    - previous: @ 553dcba
    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
2026-08-28 data: refresh landing artifacts (GFS run @ 2026-08-28 12:04 UTC)
    - previous: @ 40afe20
    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
2026-08-28 data: refresh landing artifacts (GFS run @ 2026-08-28 22:13 UTC)
    - previous: @ cf3ed43
    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
2026-08-28 data: refresh landing artifacts (GFS run @ 2026-08-28 22:15 UTC)
    - previous: @ 5c9cdae
    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
2026-08-28 data: refresh landing artifacts (GFS run @ 2026-08-28 22:34 UTC)
    - previous: @ a977522
    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
2026-08-29 data: refresh landing artifacts (GFS run @ 2026-08-29 07:19 UTC)
    - previous: @ 031ad37
    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
2026-08-29 data: refresh landing artifacts (GFS run @ 2026-08-29 16:52 UTC)
    - previous: @ 2c6d385
    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
2026-08-29 data: refresh landing artifacts (GFS run @ 2026-08-29 21:06 UTC)
    - previous: @ 002b330
    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
2026-08-30 data: refresh landing artifacts (GFS run @ 2026-08-30 05:43 UTC)
    - previous: @ 4ef8a8c
    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
2026-08-30 data: refresh landing artifacts (GFS run @ 2026-08-30 12:10 UTC)
    - previous: @ 23391b6
    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
2026-08-30 data: refresh landing artifacts (GFS run @ 2026-08-30 16:56 UTC)
    - previous: @ fe7e8c5
    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
2026-08-30 data: refresh landing artifacts (GFS run @ 2026-08-30 21:27 UTC)
    - previous: @ 3153493
    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
2026-08-31 data: refresh landing artifacts (GFS run @ 2026-08-31 14:21 UTC)
    - previous: @ ec489bf
    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
2026-08-31 data: refresh landing artifacts (GFS run @ 2026-08-31 23:00 UTC)
    - previous: @ c056802
    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
2026-09-01 data: refresh landing artifacts (GFS run @ 2026-09-01 05:32 UTC)
    - previous: @ 4bc3415
    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
2026-09-01 data: refresh landing artifacts (GFS run @ 2026-09-01 11:58 UTC)
    - previous: @ c362673
    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
2026-09-01 data: refresh landing artifacts (GFS run @ 2026-09-01 16:52 UTC)
    - previous: @ d1666a9
    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
2026-09-01 data: refresh landing artifacts (GFS run @ 2026-09-01 21:15 UTC)
    - previous: @ 816025e
    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
2026-09-02 data: refresh landing artifacts (GFS run @ 2026-09-02 04:58 UTC)
    - previous: @ 1ec746e
    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
2026-09-02 data: refresh landing artifacts (GFS run @ 2026-09-02 11:39 UTC)
    - previous: @ 0e4e253
    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
2026-09-02 data: refresh landing artifacts (GFS run @ 2026-09-02 16:49 UTC)
    - previous: @ e9b1d19
    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
2026-09-02 data: refresh landing artifacts (GFS run @ 2026-09-02 21:13 UTC)
    - previous: @ 7a00791
    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
2026-09-03 data: refresh landing artifacts (GFS run @ 2026-09-03 04:11 UTC)
    - previous: @ 0997862
    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
2026-09-03 data: refresh landing artifacts (GFS run @ 2026-09-03 04:57 UTC)
    - previous: @ 45c16f3
    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
2026-09-03 data: refresh landing artifacts (GFS run @ 2026-09-03 09:52 UTC)
    - previous: @ 8894ffc
    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
2026-09-03 data: refresh landing artifacts (GFS run @ 2026-09-03 11:37 UTC)
    - previous: @ bae8f2b
    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
2026-09-03 data: refresh landing artifacts (GFS run @ 2026-09-03 16:38 UTC)
    - previous: @ 887fff5
    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
2026-09-03 data: refresh landing artifacts (GFS run @ 2026-09-03 21:16 UTC)
    - previous: @ 6488d5f
    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
2026-09-04 data: refresh landing artifacts (GFS run @ 2026-09-04 05:00 UTC)
    - previous: @ 4c091e8
    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
2026-09-04 data: refresh landing artifacts (GFS run @ 2026-09-04 11:39 UTC)
    - previous: @ ef14138
    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
2026-09-04 data: refresh landing artifacts (GFS run @ 2026-09-04 16:34 UTC)
    - previous: @ d9d6c96
    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
2026-09-04 data: refresh landing artifacts (GFS run @ 2026-09-04 20:58 UTC)
    - previous: @ 3713f9f
    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
2026-09-05 data: refresh landing artifacts (GFS run @ 2026-09-05 04:52 UTC)
    - previous: @ 28362e4
    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
2026-09-05 data: refresh landing artifacts (GFS run @ 2026-09-05 10:53 UTC)
    - previous: @ 0020081
    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
2026-09-05 data: refresh landing artifacts (GFS run @ 2026-09-05 15:29 UTC)
    - previous: @ 4239523
    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
2026-09-05 data: refresh landing artifacts (GFS run @ 2026-09-05 20:39 UTC)
    - previous: @ b668ac5
    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
2026-09-06 data: refresh landing artifacts (GFS run @ 2026-09-06 05:00 UTC)
    - previous: @ 5d0d38a
    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
2026-09-06 data: refresh landing artifacts (GFS run @ 2026-09-06 11:17 UTC)
    - previous: @ 2e075a9
    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
2026-09-06 data: refresh landing artifacts (GFS run @ 2026-09-06 15:42 UTC)
    - previous: @ c2b9701
    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
2026-09-06 data: refresh landing artifacts (GFS run @ 2026-09-06 20:44 UTC)
    - previous: @ a95ede7
    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
2026-09-07 data: refresh landing artifacts (GFS run @ 2026-09-07 05:08 UTC)
    - previous: @ a76d163
    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
2026-09-07 data: refresh landing artifacts (GFS run @ 2026-09-07 12:58 UTC)
    - previous: @ 706cc91
    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
2026-09-07 data: refresh landing artifacts (GFS run @ 2026-09-07 21:44 UTC)
    - previous: @ 80e6802
    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
2026-09-08 data: refresh landing artifacts (GFS run @ 2026-09-08 05:05 UTC)
    - previous: @ 0465cbc
    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
2026-09-08 data: refresh landing artifacts (GFS run @ 2026-09-08 11:41 UTC)
    - previous: @ dc81333
    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
2026-09-08 data: refresh landing artifacts (GFS run @ 2026-09-08 16:49 UTC)
    - previous: @ 082a117
    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
2026-09-08 data: refresh landing artifacts (GFS run @ 2026-09-08 21:21 UTC)
    - previous: @ e536a40
    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
2026-09-09 data: refresh landing artifacts (GFS run @ 2026-09-09 05:04 UTC)
    - previous: @ 2ece855
    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
2026-09-09 data: refresh landing artifacts (GFS run @ 2026-09-09 11:46 UTC)
    - previous: @ a839ce8
    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
2026-09-09 data: refresh landing artifacts (GFS run @ 2026-09-09 16:51 UTC)
    - previous: @ 744710e
    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
2026-09-09 data: refresh landing artifacts (GFS run @ 2026-09-09 21:07 UTC)
    - previous: @ fccfb32
    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
2026-09-10 data: refresh landing artifacts (GFS run @ 2026-09-10 05:07 UTC)
    - previous: @ 51b5577
    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
2026-09-10 data: refresh landing artifacts (GFS run @ 2026-09-10 11:44 UTC)
    - previous: @ 292ee1d
    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
2026-09-10 data: refresh landing artifacts (GFS run @ 2026-09-10 16:39 UTC)
    - previous: @ 16096e1
    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
2026-09-10 data: refresh landing artifacts (GFS run @ 2026-09-10 21:07 UTC)
    - previous: @ dfbe4ec
    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
